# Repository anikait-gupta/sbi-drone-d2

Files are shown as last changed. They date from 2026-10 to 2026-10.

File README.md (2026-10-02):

# sbi-drone-d2

SBI UT club drone. Phase 1 is a quadcopter that flies on an ArduPilot stack capable of autonomous missions. It has no payload or onboard computer yet. The motors, battery and power system are sized for the heavier Phase 2 build, so those can be added later without replacing anything.

## What's here

| Path | Contents |
| :-- | :-- |
| `SBI_Drone_Phase1_Parts.xlsx` | Phase 1 parts list: vendor, price (checked 2026-09-30), link, and why each part was chosen |
| `wiring/` | Phase 1 wiring: block diagram, KiCad schematic, wiring table, and the checks that keep them in sync. See [`wiring/README.md`](wiring/README.md) |

## Phase 1 build

- **Flight controller:** Holybro Pixhawk 6C with PM07 power module and M10 GPS, running ArduPilot
- **Propulsion:** 4x BrotherHobby Avenger 3110 730KV, 4x Hobbywing XRotor Pro 50A ESCs, 10x4.5 props, quad X
- **Power:** 6S 5000 mAh LiPo, XT60
- **RC link:** RadioMaster Pocket (ELRS 2.4 GHz) with an RP3-H receiver on TELEM3
- **Frame:** custom CNC carbon plate, about 450-500 mm wheelbase (CAD in progress)

Not yet priced: frame, McMaster hardware, LiPo bag, microSD card. The onboard computer is deferred to Phase 2.

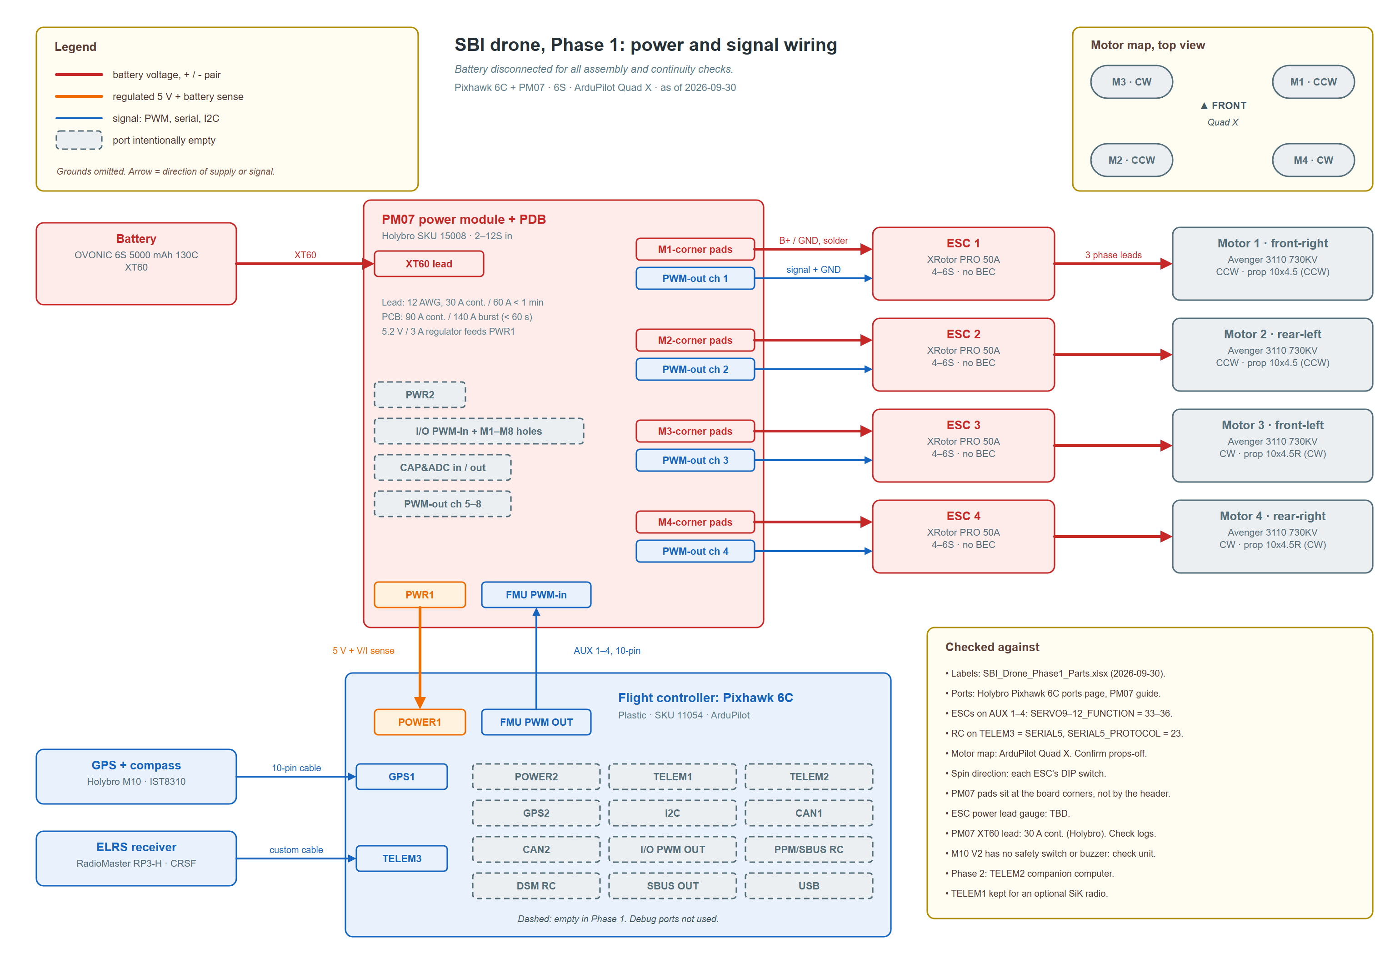
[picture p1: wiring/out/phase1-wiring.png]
Phase 1 wiring block diagram


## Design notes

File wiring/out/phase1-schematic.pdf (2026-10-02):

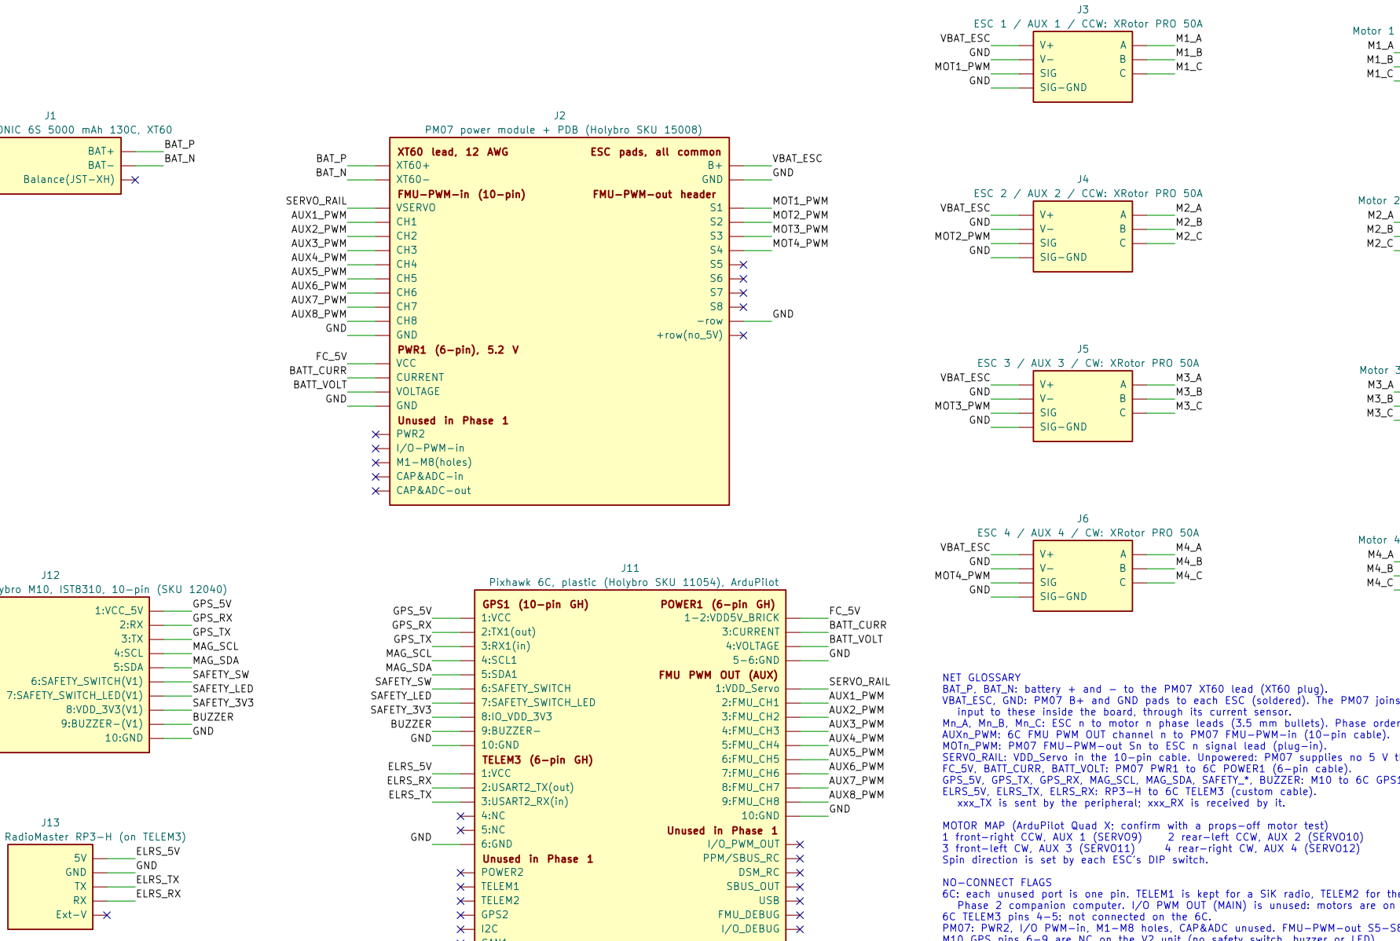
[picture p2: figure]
5V Ext-V GND; Balance(JST-XH) BAT-; BAT+; 1:VCC_5V 2:RX; 3:TX 4:SCL 5:SDA 6:SAFETY_SWITCH(V1); 7:SAFETY_SWITCH_LED(V1) 8:VDD_3V3(V1) 9:BUZZER-(V1) 10:GND; ESC pads, all common; FMU-PWM-out header GND; VSERVO; I/O-PWM-in; M1-M8(holes); -row; S1 S2 S3 S4 S5 S6 S7 S8 +row(no_5V) CURRENT GND; VCC; VOLTAGE PWR2; 1:VDD_Servo 2:FMU_CH1; 3:FMU_CH2 4:FMU_CH3 5:FMU_CH4 6:FMU_CH5 7:FMU_CH6 8:FMU_CH7 9:FMU_CH8 10:GND; FMU_DEBUG; 1:VCC 2:TX1(out) 3:RX1(in) 4:SCL1; 5:SDA1 6:SAFETY_SWITCH 7:SAFETY_SWITCH_LED 8:IO_VDD_3V3 9:BUZZER- 10:GND; GPS2; I/O_DEBUG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

ELRS receiver: RadioMaster RP3-H (on TELEM3)

J1 Battery: OVONIC 6S 5000 mAh 130C, XT60

J12 GPS + compass: Holybro M10, IST8310, 10-pin (SKU 12040) | XT60 lead, 12 AWG

### FMU-PWM-in (10-pin) PWR1 (6-pin), 5.2 V Unused in Phase 1

# CAP&ADC-in CAP&ADC-out CH1 CH2 CH3 CH4 CH5 CH6 CH7 CH8 GND

J2 PM07 power module + PDB (Holybro SKU 15008) | AB

C

J9 Motor 3 front-left CW: Avenger 3110 730KV GPS1 (10-pin GH) TELEM3 (6-pin GH) Unused in Phase 1 | POWER1 (6-pin GH) FMU PWM OUT (AUX) Unused in Phase 1 CAN1 CAN2 | DSM_RC
J11 Pixhawk 6C, plastic (Holybro SKU 11054), ArduPilot | AB
| C

J10 Motor 4 rear-right CW: Avenger 3110 730KV

AB

C

J7 Motor 1 front-right CCW: Avenger 3110 730KV

AB

C

J8 Motor 2 rear-left CCW: Avenger 3110 730KV

M4_C M3_C M2_C Battery disconnected for all assembly and continuity checks. As of 2026-09-30. Ground truth: wiring/wiring-table.md

# SBI drone, Phase 1: wiring schematic

NET GLOSSARY BAT_P, BAT_N: battery + and - to the PM07 XT60 lead (XT60 plug).

VBAT_ESC, GND: PM07 B+ and GND pads to each ESC (soldered). The PM07 joins its
input to these inside the board, through its current sensor. Mn_A, Mn_B, Mn_C: ESC n to motor n phase leads (3.5 mm bullets). Phase order is arbitrary. AUXn_PWM: 6C FMU PWM OUT channel n to PM07 FMU-PWM-in (10-pin cable). MOTn_PWM: PM07 FMU-PWM-out Sn to ESC n signal lead (plug-in). SERVO_RAIL: VDD_Servo in the 10-pin cable. Unpowered: PM07 supplies no 5 V there. FC_5V, BATT_CURR, BATT_VOLT: PM07 PWR1 to 6C POWER1 (6-pin cable).

GPS_5V, GPS_TX, GPS_RX, MAG_SCL, MAG_SDA, SAFETY_*, BUZZER: M10 to 6C GPS1 (10-pin cable).
ELRS_5V, ELRS_TX, ELRS_RX: RP3-H to 6C TELEM3 (custom cable). xxx_TX is sent by the peripheral; xxx_RX is received by it. MOTOR MAP (ArduPilot Quad X; confirm with a props-off motor test) 1 front-right CCW, AUX 1 (SERVO9) | 2 rear-left CCW, AUX 2 (SERVO10) 3 front-left CW, AUX 3 (SERVO11) | 4 rear-right CW, AUX 4 (SERVO12)

Spin direction is set by each ESC's DIP switch. NO-CONNECT FLAGS

6C: each unused port is one pin. TELEM1 is kept for a SiK radio, TELEM2 for the Phase 2 companion computer. I/O PWM OUT (MAIN) is unused: motors are on AUX. 6C TELEM3 pins 4-5: not connected on the 6C. PM07: PWR2, I/O PWM-in, M1-M8 holes, CAP&ADC unused. FMU-PWM-out S5-S8: four ESCs only. M10 GPS pins 6-9 are NC on the V2 unit (no safety switch, buzzer or LED).

Battery balance lead: charger only. RP3-H Ext-V: unused. ArduPilot: SERVO9-12_FUNCTION = 33-36, SERVO1-4_FUNCTION = 0, SERIAL5_PROTOCOL = 23. ESC power lead gauge: TBD.

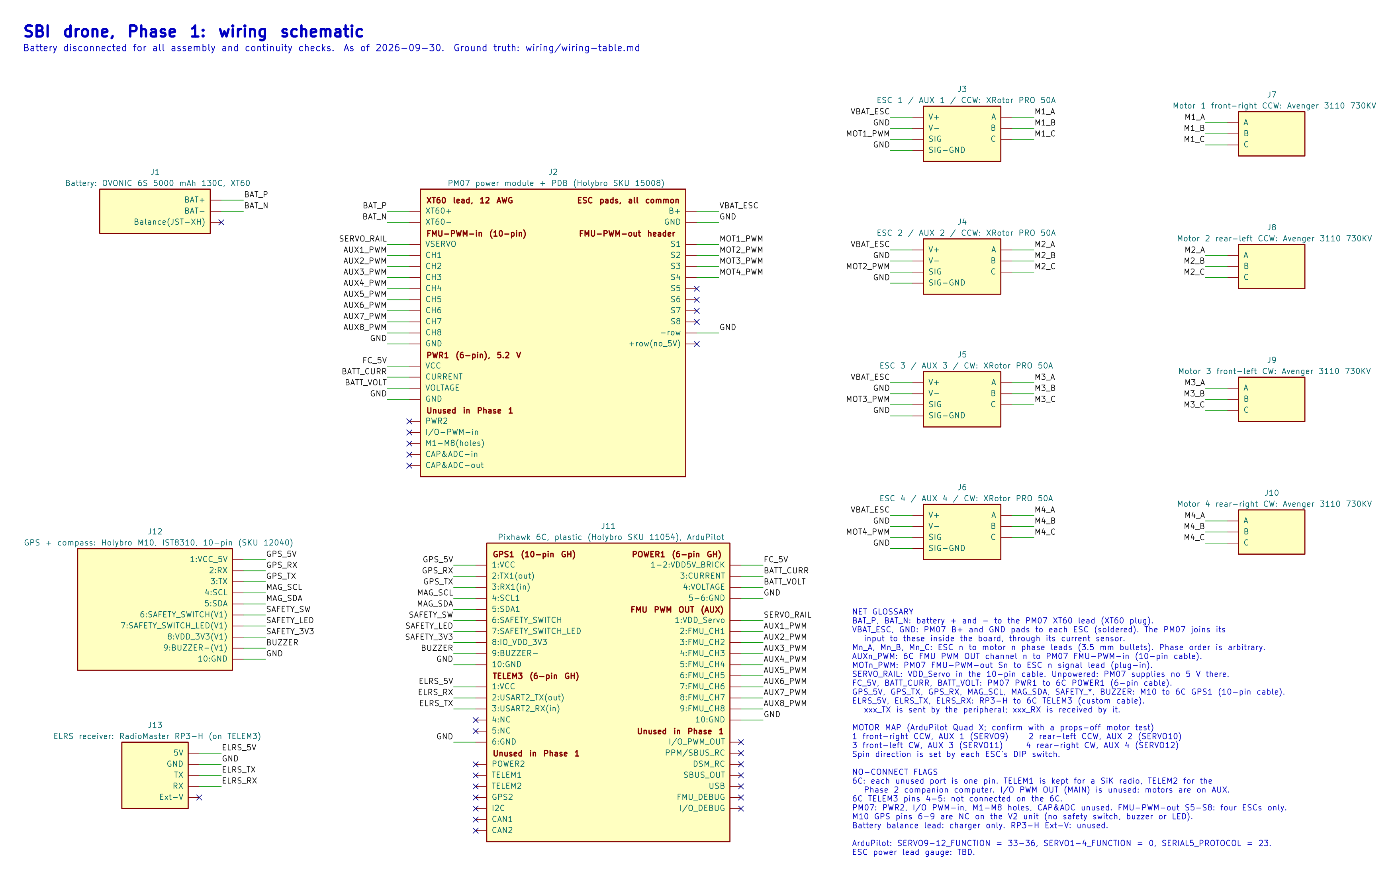
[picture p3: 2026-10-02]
wiring/out/phase1-schematic.png

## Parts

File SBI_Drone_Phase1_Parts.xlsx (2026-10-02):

SBI UT Club Drone - Phase 1 Parts List
Prices and stock verified on vendor pages 2026-09-30. Blue = input; yellow = to fill in / decide.
# | Category | Item | Vendor | Qty | Unit price | Line total | Link | Notes / status | Justification
1 | Flight controller | Pixhawk 6C Plastic + PM07 (SKU 11054+15008) | Holybro | 1 | $242.99 |  | Open (https://holybro.com/products/pixhawk-6c) | Price rose from $209.98. PM07 doubles as PDB. | Runs ArduPilot, which gives us the autonomous waypoint missions and return-to-launch on lost link that Anikait asked for. Two redundant IMUs, both temperature-controlled and vibration-isolated. Spare ports (TELEM1/2, GPS2, CAN) leave room for the Phase 2 companion computer, rangefinder and RTK without changing boards. The PM07 reads battery voltage/current for the low-battery failsafe and doubles as the power distribution board (rated 2-12S), so no separate PDB. Plastic case is the lighter 6C version (34.6 g vs 59.3 g aluminum).
2 | Flight controller | M10 GPS, IST8310, Standard 10-pin (SKU 12040) | Holybro | 1 | $43.99 |  | Open (https://holybro.com/products/m10-gps) | Includes carbon GPS mount. | GPS is required for position hold, waypoint missions and return-to-launch. The IST8310 compass sits on the mast, away from motor and battery current, so heading is cleaner than with the FC's internal compass. Same vendor and standard 10-pin plug as the 6C, so it plugs into GPS1 with no cable work. RTK was 'if budget allows'; GPS2 stays free for it later.
3 | Propulsion | BrotherHobby Avenger 3110 730KV (select 730) | AeromotorFPV | 5 | $29.50 |  | Open (https://www.aeromotorfpv.com/product/brotherhobby-avenger-3110-brushless-motor-cw-730kv-900kv-for-6s-m5-shaft-19x19mm-mount/) | 4 + 1 spare. Sale price ($59 list). | Sized for Phase 2 weight, not just Phase 1: at ~2.2-2.5 kg all-up we need ~1.1-1.25 kg max thrust per motor for a 2:1 thrust-to-weight ratio. Vendor test shows 3017 gf peak (on a 10x5 tri-blade), so there is margin even with our lighter-loading 2-blade prop. 730 KV is the right speed for 10" props on 6S (the 900 KV version is meant for 8-9" props). T-Motor MN3110 rejected as an unneeded premium for Phase 1. Fifth motor is a spare so one bad motor doesn't ground the drone.
4 | Propulsion | Hobbywing XRotor PRO 50A wire-leaded ESC (dual pack) | Hobbywing Direct | 2 | $74.99 |  | Open (https://www.hobbywingdirect.com/collections/xrotor-pro-esc/products/xrotor-pro-50a-esc-dual-pack) | 4-6S, 3.5 mm bullets on motor side, no BEC. | Four separate ESCs rather than a 4-in-1 board (team decision): a failed ESC is one cheap swap, not a whole board. 50 A continuous / 100 A peak gives headroom over the motor's 37.6 A max; 40 A ESCs were too tight at full throttle. Rated 4-6S. Motor side ships with 3.5 mm bullets (less soldering), and a DIP switch sets spin direction, so all five motors can be the same part. Standard PWM input works with ArduPilot on the 6C. No BEC needed because the PM07 powers the FC.
5 | Propulsion | HQProp MR 10x4.5 CCW (single prop) | HQProp | 6 | $2.91 |  | Open (https://hqprop.com/multi-rotor-prop-p0155.html) | Ships from China; shipping not shown. GetFPV out of stock. | 10" diameter matches the 730 KV / 6S motors and the 450-500 mm frame. Glass-fiber reinforced nylon is cheap and more forgiving in crashes than carbon; carbon props are deferred to Phase 2 benchmarking. A quad X needs 2 CCW + 2 CW per set, so 6 of each = 3 full sets, since props are the most common crash casualty. 5 mm ring fits the Avenger's M5 shaft. Bought direct because GetFPV is out of stock.
6 | Propulsion | HQProp MR 10x4.5R CW (single prop) | HQProp | 6 | $2.91 |  | Open (https://hqprop.com/multi-rotor-pusher-prop-10x45rcw-p0300.html) | Ships from China; 5 mm ring included. | CW half of each prop set (see #5). A quad X spins two motors each way so their torques cancel, which is what lets the FC control yaw.
7 | Propulsion | JFtech 3.5 mm gold bullets, 20 pairs + heat shrink | Amazon | 1 | $7.99 |  | Open (https://www.amazon.com/dp/B07C69VDV3) | Males go on bare Avenger motor leads. | Avenger motors ship with bare leads; the ESCs already have 3.5 mm bullets. Putting matching bullets on the 15 motor leads (5 motors x 3) makes motors plug-and-unplug, so a bad motor is swapped without desoldering. 20 pairs covers that with spares, and the heat shrink insulates each joint.
8 | Power | OVONIC 6S 5000mAh 130C XT60 (2-pack) | Amazon | 1 | $110.99 |  | Open (https://www.amazon.com/dp/B0DNLWDTDT) | PENDING OK: replaces CNHL (out of US stock). XT60 = no adapter. | 6S matches the 730 KV motors: higher voltage means less current for the same power, so less heat in the ESCs and wiring. XT60 plugs straight into the PM07, so no adapter (one less joint to loosen or heat up). 130C is far above our peak draw (~150 A, four motors at 37.6 A). The 2-pack works out to $55.50 per pack, about what one CNHL cost, and the second pack doubles flight time per test session since a recharge takes ~2 h.
9 | Charging | SkyRC B6 Neo charger | Amazon | 1 | $37.50 |  | Open (https://www.amazon.com/dp/B0CCT2WGNS) | Sold by YEERSINS, ships from Amazon. | LiPos have to be balance charged on a proper hobby charger. The B6 Neo does 1-6S balance charging plus storage-voltage mode, which extends pack life between test days, and it's one of the cheapest 6S-capable chargers. Runs from USB-C PD (80 W, ~3 A, ~1.7-2 h per pack) or a DC supply up to 200 W if we want faster charging later.
10 | Charging | VUOHOEG 100W USB-C PD charger (built-in cable) | Amazon | 1 | $18.89 |  | Open (https://www.amazon.com/dp/B0FBG4BY5X) | Powers B6 Neo at 80W via USB-C. | The B6 Neo has no built-in AC power; it needs a 100 W (20 V / 5 A) USB-C PD source or a DC supply. This is the cheapest working option and its cable is built in and 5 A rated, so no separate 5 A cable to buy. A 24 V DC supply (~$30) would charge faster but isn't needed yet. Unbranded, but 4.3 stars over 692 reviews.
11 | RC link | RadioMaster Pocket, Charcoal / ELRS / FCC (M2) | RadioMaster | 1 | $71.50 |  | Open (https://radiomasterrc.com/products/pocket-radio-controller-m2) | Batteries not included. | A handheld radio is needed for manual takeoff/landing while tuning and as the safety pilot's override during autonomous flights; nobody on the team owns one. ELRS 2.4 GHz has long range, low latency and sends telemetry (link quality, battery voltage) back to the radio. The Pocket is one of the cheapest full EdgeTX radios. FCC version for US use; Mode 2 is the standard US stick layout. FlySky i6X rejected: no telemetry and shorter range.
12 | RC link | RadioMaster 18650 3200mAh (2 pcs) | RadioMaster | 1 | $11.99 |  | Open (https://radiomasterrc.com/products/18650-3200mah-3-7v-battery-2pcs-for-tx16s-boxer-tx12-mt12-radios) | Must be bought in same order as radio. | The Pocket runs on 2x 18650 cells that aren't included. RadioMaster's own cells are made for its radios, and ordering them with the Pocket and RP3-H keeps it to one shipment.
13 | RC link | RadioMaster RP3-H receiver (FCC) | RadioMaster | 1 | $19.99 |  | Open (https://radiomasterrc.com/products/rp3-h-expresslrs-2-4ghz-nano-receiver) | JST-GH 4-pin cables included. | ELRS receiver that pairs with the Pocket. One serial (CRSF) cable to TELEM3 carries both stick inputs and telemetry, and ArduPilot supports it natively; losing the link triggers the RC failsafe (RTL). Two diversity antennas for a steadier link than single-antenna receivers, 100 mW telemetry, 5.1 g.
14 | RC link | elechawk GH1.25 to Dupont pre-crimped cable kit | Amazon | 1 | $20.99 |  | Open (https://amazon.com/Dupont2-54-Pre-Crimped-Connectors-Pixhawk4-Pixhawk2/dp/B087N4GY8Z) | Build 6-pin GH cable to TELEM port. | The RP3-H comes with 4-pin JST-GH cables, but the 6C's TELEM ports are 6-pin JST-GH. Pre-crimped GH wires and housings let us build the right 6-pin cable without a crimping tool. Leftovers cover Phase 2 wiring (companion computer on TELEM2, rangefinder).
Still to price (fill in when quoted)
15 | Frame | CNC carbon frame (CNC Madness quote) | CNC Madness | 1 |  |  |  | Needs CAD; ~450-500 mm class. | Team chose a custom frame over off-the-shelf kits (S500/X500) so it can be laid out for the Phase 2 payload mount and compute bay from the start. CNC carbon plate is stiff and light, and a ~450-500 mm wheelbase clears 10" props. CNC Madness turns quotes around quickly, so the price comes once CAD is done.
16 | Hardware | McMaster hardware (M3 standoffs/screws, M5 nyloc nuts, etc.) | McMaster-Carr | 1 |  |  |  | Depends on frame design. | Fasteners and standoffs to assemble the frame and mount the electronics, plus spare M5 nyloc nuts for the props (nyloc won't vibrate loose). McMaster lists exact dimensions and ships fast; quantities get set once the CAD is final.
17 | Misc | LiPo safety bag |  | 1 |  |  |  | If club has none. | Damaged or overcharged LiPos can catch fire. Charging and storing packs in a fire-resistant bag is standard practice, and we will have two 6S packs in a shared campus lab. Skip if the club already has one.
18 | Misc | microSD card (<=32 GB) for flight logs |  | 1 |  |  |  | Not listed in 6C box contents. | ArduPilot writes its flight logs to this card; we need them to tune PIDs, check vibration and work out what went wrong after a crash. The 6C box contents don't list a card. 32 GB or smaller ships formatted FAT32, which the FC reads without reformatting.
 |  |  |  | Verified subtotal
 |  |  |  | Still-to-price subtotal
 |  |  |  | Budget |  | $1300.00
 |  |  |  | Est. sales tax rate |  | 8.25%
 |  |  |  | Est. shipping (all vendors) |  | $0.00
 |  |  |  | Est. tax
 |  |  |  | Est. grand total
 |  |  |  | Remaining budget

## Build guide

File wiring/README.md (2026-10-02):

# Phase 1 wiring figures

There are two figures of the same wiring, built from two separate sources. The method comes from `drone-docs/outputs/wiring-pipeline-handoff.md`.

| Figure | For | Source of truth | Output |
| :-- | :-- | :-- | :-- |
| Block diagram | Assembly: what connects to what, colour coded by rail | `phase1_wiring.py`, drawn by `wiring_diagram.py` | `out/phase1-wiring.svg`, `.drawio`, `.png` |
| Schematic | Verification: pin names and named nets | `kicad/sbi_phase1.kicad_sch` and `kicad/sbi_phase1.kicad_sym` | `out/phase1-schematic.pdf`, `.png` |

Both are drawn from `wiring-table.md`, which cites a source for every conductor.

## Rebuild and check

```
pip install playwright pymupdf pillow
playwright install chromium
python build.py
```

`build.py` runs the layout linter, KiCad ERC, and the netlist check against `kicad/expected-nets.txt`, then exports the PDF and PNG. It exits 1 if any check fails. After it passes, look at both PNGs: the checks cover geometry and connectivity, not whether the figure is correct.

## Changing a wiring fact

1. Change it in `wiring-table.md`.
2. Change it in `phase1_wiring.py`.
3. Change it in the schematic (KiCad GUI, or the text file), then the matching line in `kicad/expected-nets.txt`.
4. Run `python build.py`, then grep all of the above for the old value.

`kicad/gen_schematic.py` wrote the first version of the KiCad files. Once anyone edits the schematic in KiCad, do not run it again: it overwrites the schematic, the library and the project file.

The `.drawio` file is for anyone who wants to hand-tweak the layout in diagrams.net. A hand edit is lost the next time `phase1_wiring.py` runs.

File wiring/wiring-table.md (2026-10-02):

# Phase 1 wiring table

Ground truth for both wiring figures (`out/phase1-wiring.*` and `kicad/sbi_phase1.kicad_sch`). If a wiring fact changes, change it here first, then in `phase1_wiring.py`, then in the schematic, and run the netlist check.

As of 2026-09-30. Battery disconnected for all assembly and continuity checks.

## Sources

| Key | Source |
| :-- | :-- |
| BOM | `SBI_Drone_Phase1_Parts.xlsx`, prices and stock verified 2026-09-30 |
| 6C | Holybro, [Pixhawk 6C Ports](https://docs.holybro.com/autopilot/pixhawk-6c/pixhawk-6c-ports) |
| PM07 | Holybro, [PM07 Quick Start Guide](https://docs.holybro.com/power-module-and-pdb/power-module/pm07-quick-start-guide), including its board-tracing image |
| GPS | Holybro, [Standard M10 GPS overview](https://docs.holybro.com/gps-and-rtk-system/m8n-m9n-m10-gps/standard-m10-m9n-m8n-gps/overview) and [pinout](https://docs.holybro.com/gps-and-rtk-system/m8n-m9n-m10-gps/standard-m10-m9n-m8n-gps/pinout) images |
| AP | ArduPilot, [Holybro Pixhawk 6C](https://ardupilot.org/copter/docs/common-holybro-pixhawk6C.html) and [Connect ESCs and motors](https://ardupilot.org/copter/docs/connect-escs-and-motors.html) (Quad X image `m_01_01_quad_x1.svg`) |
| HW | Hobbywing, [XRotor PRO 50A dual pack](https://www.hobbywingdirect.com/products/xrotor-pro-50a-esc-dual-pack) |
| RM | RadioMaster, [RP3-H](https://radiomasterrc.com/products/rp3-h-expresslrs-2-4ghz-nano-receiver) |
| TEAM | Decisions made 2026-09-30: OVONIC battery approved, ELRS on TELEM3, ArduPilot Quad X map, ESC signals through the PM07 AUX header |

## Components

| Ref | Component | Label source |
| :-- | :-- | :-- |
| J1 | Battery: OVONIC 6S 5000 mAh 130C, XT60 | BOM #8, TEAM |
| J2 | PM07 power module + PDB (Holybro SKU 15008) | BOM #1 |
| J3 to J6 | ESC 1 to 4: Hobbywing XRotor PRO 50A, 4 to 6S, no BEC | BOM #4, HW |
| J7 to J10 | Motor 1 to 4: BrotherHobby Avenger 3110 730KV | BOM #3 |
| J11 | Pixhawk 6C, plastic (Holybro SKU 11054), ArduPilot | BOM #1 |
| J12 | GPS + compass: Holybro M10, IST8310, standard 10-pin (SKU 12040) | BOM #2, GPS |
| J13 | ELRS receiver: RadioMaster RP3-H | BOM #13, RM |

## Conductors

### Battery voltage

| ID | From | To | Carries | Connector or joint | Gauge | Source |
| :-- | :-- | :-- | :-- | :-- | :-- | :-- |
| P1 | J1 battery lead | J2 PM07 XT60 lead | BAT+ / BAT- | XT60 plug | PM07 lead 12 AWG; battery lead not recorded | BOM, PM07 |
| P2 | J2 B+ / GND pads | J3 ESC 1 power leads | V+ / V- | Solder to pads | TBD (not on the Hobbywing page) | BOM, PM07 |
| P3 | J2 B+ / GND pads | J4 ESC 2 power leads | V+ / V- | Solder to pads | TBD | BOM, PM07 |
| P4 | J2 B+ / GND pads | J5 ESC 3 power leads | V+ / V- | Solder to pads | TBD | BOM, PM07 |
| P5 | J2 B+ / GND pads | J6 ESC 4 power leads | V+ / V- | Solder to pads | TBD | BOM, PM07 |
| P6 to P9 | ESC n motor output, 3 leads | Motor n phase leads, 3 | Phase A, B, C | ESC side has 3.5 mm bullets fitted; solder JFtech 3.5 mm male bullets onto the bare motor leads | Not recorded | BOM #3, #4, #7, HW |

- The PM07 has four corner pad groups, each `GND B+ B+ GND`, so each group serves two ESCs. All B+ pads are common and all GND pads are common. Suggested: put ESC n on the group at the corner marked `Mn`. Seen from above, those corners match the Quad X map if the XT60 edge of the PM07 faces the rear (inferred from the PM07 silkscreen, not stated by Holybro).
- Holybro rates the PM07's XT60 and 12 AWG lead at 30 A continuous and 60 A for under 1 minute. The PCB is rated 90 A continuous and 140 A burst (under 60 s). See open item 3.
- Motor phase order is arbitrary. Each ESC's DIP switch sets spin direction.

### Regulated 5 V and battery sense

| ID | From | To | Carries | Connector | Source |
| :-- | :-- | :-- | :-- | :-- | :-- |
| F1 | J2 PWR1 | J11 POWER1 | Pins 1-2 VCC 5 V, 3 CURRENT, 4 VOLTAGE, 5-6 GND | 6-pin JST-GH cable (supplied with PM07) | PM07, 6C |

- The PM07 supplies regulated 5.2 V at up to 3 A. ArduPilot defaults for POWER1: `BATT_MONITOR=4`, `BATT_VOLT_PIN=8`, `BATT_CURR_PIN=4`, `BATT_VOLT_MULT=18.182`, `BATT_AMP_PERVLT=36.364` (AP).

### Signal

| ID | From | To | Carries | Connector | Source |
| :-- | :-- | :-- | :-- | :-- | :-- |
| S1 | J11 FMU PWM OUT (AUX) | J2 FMU-PWM-in | Pin 1 VDD_Servo, 2-9 FMU_CH1-8, 10 GND | 10-pin JST-GH cable | 6C, PM07, TEAM |
| S2 | J2 FMU-PWM-out channel 1 (S and -) | J3 ESC 1 signal lead | AUX 1 PWM + signal ground | ESC signal plug onto the 3-pin header | PM07, TEAM |
| S3 | J2 FMU-PWM-out channel 2 | J4 ESC 2 signal lead | AUX 2 PWM | as S2 | PM07, TEAM |
| S4 | J2 FMU-PWM-out channel 3 | J5 ESC 3 signal lead | AUX 3 PWM | as S2 | PM07, TEAM |
| S5 | J2 FMU-PWM-out channel 4 | J6 ESC 4 signal lead | AUX 4 PWM | as S2 | PM07, TEAM |
| S6 | J12 GPS 10-pin | J11 GPS1 | 1 VCC, 2 RX, 3 TX, 4 SCL, 5 SDA, 6 SAFETY_SWITCH, 7 SAFETY_SWITCH_LED, 8 VDD_3V3, 9 BUZZER-, 10 GND (GPS-side names, V1) | 10-pin JST-GH cable, 26 cm, supplied | GPS, 6C |
| S7 | J13 RP3-H | J11 TELEM3 | 5V to pin 1 VCC; receiver TX to pin 3 USART2_RX; receiver RX to pin 2 USART2_TX; GND to pin 6. Pins 4-5 empty | Custom cable: RP3-H 4-pin JST-GH lead joined to a 6-pin JST-GH from the elechawk kit | BOM #13, #14, 6C, TEAM |

- The PM07's FMU-PWM-out `+` row carries no 5 V (Holybro). The XRotor PRO has no BEC and needs none, so this is fine.
- ArduPilot: `SERVO9_FUNCTION=33`, `SERVO10_FUNCTION=34`, `SERVO11_FUNCTION=35`, `SERVO12_FUNCTION=36` (Motor 1 to 4 on AUX 1 to 4). Set `SERVO1_FUNCTION` to `SERVO4_FUNCTION` to 0 so the unused MAIN outputs carry no motor signal.
- ArduPilot: TELEM3 is `SERIAL5`. Set `SERIAL5_PROTOCOL=23` (RCIN) for CRSF. ArduPilot says ELRS needs a full UART, so the RC IN port cannot be used (AP).
- RP3-H working voltage is 4.5 to 8.4 V (RM), so TELEM3's 5 V supply is in range.

## Motor map (ArduPilot Quad X)

| Motor | Position | Spin | Prop | ESC | Output |
| :-- | :-- | :-- | :-- | :-- | :-- |
| 1 | front-right | CCW | HQProp MR 10x4.5 (CCW) | ESC 1 | AUX 1 (SERVO9) |
| 2 | rear-left | CCW | HQProp MR 10x4.5 (CCW) | ESC 2 | AUX 2 (SERVO10) |
| 3 | front-left | CW | HQProp MR 10x4.5R (CW) | ESC 3 | AUX 3 (SERVO11) |
| 4 | rear-right | CW | HQProp MR 10x4.5R (CW) | ESC 4 | AUX 4 (SERVO12) |

Not yet confirmed on hardware. Confirm with a props-off motor test in Mission Planner before fitting props.

## Ports left empty in Phase 1

Every port is accounted for. These are empty on purpose.

| Board | Port | Why empty |
| :-- | :-- | :-- |
| 6C | POWER2 | One power module only |
| 6C | TELEM1 | Kept for an optional SiK telemetry radio |
| 6C | TELEM2 | Kept for the Phase 2 companion computer |
| 6C | GPS2, I2C, CAN1, CAN2 | No second GPS or other sensors in Phase 1 |
| 6C | I/O PWM OUT (MAIN) | Motors are on AUX |
| 6C | PPM/SBUS RC, DSM RC, SBUS OUT | ELRS uses TELEM3 |
| 6C | USB | Laptop link for setup only, not wired on the aircraft |
| 6C | FMU DEBUG, I/O DEBUG | Not used |
| PM07 | PWR2 | One flight controller power port in use |
| PM07 | I/O PWM-in and the M1-M8 solder holes | Motors are on AUX |
| PM07 | FMU-PWM-out channels 5-8 | Only four ESCs |
| PM07 | CAP&ADC-in, CAP&ADC-out | The 6C has no CAP&ADC port |
| PM07 | Second B+ / GND pair at each corner | Only four ESCs |
| J1 | Balance lead (JST-XH) | Charger only |
| J13 | Ext-V input | Not used |

Not wiring, but on the list: the microSD card goes in the 6C's slot. The charger, the Pocket transmitter and the 100 W USB-C supply stay on the ground.

## Open items

1. **ESC power lead gauge.** The Hobbywing page does not state it. Retailer listings say 14 AWG; check on arrival and record it here.
2. **ESC signal plug.** Confirm on arrival that the XRotor PRO signal lead ends in a plug that fits the PM07's 2.54 mm 3-pin header, with signal on S and ground on -.
3. **PM07 input lead rating.** 30 A continuous, 60 A for under 1 minute (Holybro), against four 50 A ESCs and motors listed at 37.6 A max each. Fine for hover; check measured current in the first flight logs before aggressive flying. Holybro says to change the plug and wire for higher current.
4. **GPS version.** M10 V2 has no safety switch, buzzer or safety LED (pins 6-9 are NC). The 6C has no safety switch of its own. If a V2 unit arrives, disable the safety switch in ArduPilot (`BRD_SAFETY_DEFLT=0`) and expect no buzzer.
5. **Motor map** confirmed only by a props-off motor test.
6. **Frame layout.** Wire lengths and PM07 orientation depend on the CNC frame CAD.

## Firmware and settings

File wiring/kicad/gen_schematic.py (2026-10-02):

# -*- coding: utf-8 -*-
"""Write the first version of the Phase 1 KiCad project: symbol library, schematic, project file.

Nets are built from named local labels on short wire stubs; the same name means the same net.
Every pin is either labelled or carries a no-connect flag.

After this has run, sbi_phase1.kicad_sch is the source of truth. If you edit the schematic in
KiCad, do not run this again: it overwrites the schematic, the library and the project file.

Run: python gen_schematic.py
"""
import json, os, uuid

LIB = "sbi_phase1"
NS = uuid.UUID("6f1d9a52-4c3e-4f5e-9a0b-2b7f3d1e5c80")     # fixed, so regenerating gives the same UUIDs
G = 1.27                                                   # KiCad connection grid, mm
FONT = "(effects (font (size 1.27 1.27)))"
FONT_HIDE = "(effects (font (size 1.27 1.27)) (hide yes))"


def uid(*key):
    return str(uuid.uuid5(NS, "/".join(map(str, key))))


def f(v):
    s = ("%.4f" % v).rstrip("0").rstrip(".")
    return "0" if s in ("-0", "") else s


def q(s):
    return '"%s"' % s.replace("\\", "\\\\").replace('"', '\\"').replace("\n", "\\n")


# ---------------------------------------------------------------- symbols
# Each side is a list of rows, top to bottom: ("H", heading) is a heading row drawn inside the
# body, None is an empty row, and (number, name, electrical type) is a pin. Pin numbers are
# hidden; names carry the signal, prefixed with the connector pin where Holybro documents it.
def P(num, name, etype="passive"):
    return (num, name, etype)


SYMBOLS = {
    "Battery": dict(desc="LiPo battery pack", right=[
        P("BATP", "BAT+", "power_out"), P("BATN", "BAT-"), P("BAL", "Balance(JST-XH)")]),

    "PM07": dict(desc="Holybro PM07 power module and PDB", left=[
        ("H", "XT60 lead, 12 AWG"),
        P("XT60P", "XT60+", "power_in"), P("XT60N", "XT60-"),
        ("H", "FMU-PWM-in (10-pin)"),
        P("FIN_V", "VSERVO")] + [P("FIN_CH%d" % i, "CH%d" % i, "input") for i in range(1, 9)] + [
        P("FIN_GND", "GND"),
        ("H", "PWR1 (6-pin), 5.2 V"),
        P("PWR1_VCC", "VCC", "power_out"), P("PWR1_CUR", "CURRENT", "output"),
        P("PWR1_VOLT", "VOLTAGE", "output"), P("PWR1_GND", "GND"),
        ("H", "Unused in Phase 1"),
        P("PWR2", "PWR2"), P("IOIN", "I/O-PWM-in"), P("MHOLES", "M1-M8(holes)"),
        P("CAPIN", "CAP&ADC-in"), P("CAPOUT", "CAP&ADC-out")],
        right=[
        ("H", "ESC pads, all common"),
        P("BP", "B+", "power_out"), P("BN", "GND", "power_out"),
        ("H", "FMU-PWM-out header")] + [P("OUT_S%d" % i, "S%d" % i, "output") for i in range(1, 9)] + [
        P("OUT_GND", "-row"), P("OUT_V", "+row(no_5V)")]),

    "ESC": dict(desc="Brushless ESC, no BEC", left=[
        P("VP", "V+", "power_in"), P("VN", "V-", "power_in"),
        P("SIG", "SIG", "input"), P("SGND", "SIG-GND")],
        right=[P("A", "A", "output"), P("B", "B", "output"), P("C", "C", "output")]),

    "Motor": dict(desc="Brushless motor", left=[P("A", "A"), P("B", "B"), P("C", "C")]),

    "Pixhawk6C": dict(desc="Holybro Pixhawk 6C flight controller", left=[
        ("H", "GPS1 (10-pin GH)"),
        P("GPS1_1", "1:VCC", "power_out"), P("GPS1_2", "2:TX1(out)", "output"),
        P("GPS1_3", "3:RX1(in)", "input"), P("GPS1_4", "4:SCL1", "bidirectional"),
        P("GPS1_5", "5:SDA1", "bidirectional"), P("GPS1_6", "6:SAFETY_SWITCH", "input"),
        P("GPS1_7", "7:SAFETY_SWITCH_LED", "output"), P("GPS1_8", "8:IO_VDD_3V3", "power_out"),
        P("GPS1_9", "9:BUZZER-", "output"), P("GPS1_10", "10:GND"),
        ("H", "TELEM3 (6-pin GH)"),
        P("TELEM3_1", "1:VCC", "power_out"), P("TELEM3_2", "2:USART2_TX(out)", "output"),
        P("TELEM3_3", "3:USART2_RX(in)", "input"), P("TELEM3_4", "4:NC"), P("TELEM3_5", "5:NC"),
        P("TELEM3_6", "6:GND"),
        ("H", "Unused in Phase 1")] + [P(n, n) for n in
        ("POWER2", "TELEM1", "TELEM2", "GPS2", "I2C", "CAN1", "CAN2")],
        right=[
        ("H", "POWER1 (6-pin GH)"),
        P("POWER1_1", "1-2:VDD5V_BRICK", "power_in"), P("POWER1_3", "3:CURRENT", "input"),
        P("POWER1_4", "4:VOLTAGE", "input"), P("POWER1_5", "5-6:GND", "power_in"),
        ("H", "FMU PWM OUT (AUX)"),
        P("FMU_1", "1:VDD_Servo")] + [P("FMU_%d" % (i + 1), "%d:FMU_CH%d" % (i + 1, i), "output")
                                      for i in range(1, 9)] + [
        P("FMU_10", "10:GND"),
        ("H", "Unused in Phase 1")] + [P(n.replace("/", "_"), n) for n in
        ("I/O_PWM_OUT", "PPM/SBUS_RC", "DSM_RC", "SBUS_OUT", "USB", "FMU_DEBUG", "I/O_DEBUG")]),

    "GPS_M10": dict(desc="Holybro M10 GPS, standard 10-pin", right=[
        P("1", "1:VCC_5V", "power_in"), P("2", "2:RX", "input"), P("3", "3:TX", "output"),
        P("4", "4:SCL", "bidirectional"), P("5", "5:SDA", "bidirectional"),
        P("6", "6:SAFETY_SWITCH(V1)"), P("7", "7:SAFETY_SWITCH_LED(V1)"),
        P("8", "8:VDD_3V3(V1)"), P("9", "9:BUZZER-(V1)"), P("10", "10:GND", "power_in")]),

    "ELRS_RX": dict(desc="ExpressLRS receiver, CRSF", right=[
        P("5V", "5V", "power_in"), P("GND", "GND", "power_in"), P("TX", "TX", "output"),
        P("RX", "RX", "input"), P("EXTV", "Ext-V")]),
}
CHAR = 1.12          # mm per character at 1.27 mm text, a deliberately wide estimate


def geometry(sym):
    left, right = sym.get("left", []), sym.get("right", [])
    rows = max(len(left), len(right))
    # headings are bold, so count them wider than pin names
    width = lambda side: max([len(r[1]) * (1.2 if r[0] == "H" else 1.0) for r in side if r] or [0])
    need = (width(left) + width(right)) * CHAR + 8
    w = 2 * int(-(-need // (2 * G)))                       # body width in grid units, even
    w = max(w, 12)
    top = rows + 1                                         # grid units, body is symmetric
    pins = []                                              # (num, name, type, side, x, y) in mm, y up
    for side, rows_ in (("L", left), ("R", right)):
        for k, r in enumerate(rows_):
            if r and r[0] != "H":
                x = (-(w // 2) - 2) * G if side == "L" else ((w // 2) + 2) * G
                pins.append((r[0], r[1], r[2], side, x, (rows - 1 - 2 * k) * G))
    heads = [(side, (rows - 1 - 2 * k) * G, r[1])
             for side, rows_ in (("L", left), ("R", right)) for k, r in enumerate(rows_)
             if r and r[0] == "H"]
    return dict(w=w * G, top=top * G, pins=pins, heads=heads)


def symbol_sexpr(name, sym, prefix=""):
    g = geometry(sym)
    hw, top = g["w"] / 2, g["top"]
    out = ['(symbol %s (pin_numbers hide) (pin_names (offset 1.016)) (exclude_from_sim no) '
           '(in_bom yes) (on_board yes)' % q(prefix + name),
           '  (property "Reference" "J" (at 0 %s 0) %s)' % (f(top + 3.81), FONT),
           '  (property "Value" %s (at 0 %s 0) %s)' % (q(name), f(top + 1.27), FONT),
           '  (property "Footprint" "" (at 0 0 0) %s)' % FONT_HIDE,
           '  (property "Datasheet" "" (at 0 0 0) %s)' % FONT_HIDE,
           '  (property "Description" %s (at 0 0 0) %s)' % (q(sym["desc"]), FONT_HIDE),
           '  (symbol %s' % q("%s_0_1" % name),
           '    (rectangle (start %s %s) (end %s %s) (stroke (width 0.254) (type default)) '
           '(fill (type background)))' % (f(-hw), f(top), f(hw), f(-top))]
    for side, y, s in g["heads"]:
        x, just = (-hw + 1.27, "left") if side == "L" else (hw - 2.54, "right")
        out.append('    (text %s (at %s %s 0) (effects (font (size 1.27 1.27) (bold yes)) (justify %s)))'
                   % (q(s), f(x), f(y), just))
    out.append('  )')
    out.append('  (symbol %s' % q("%s_1_1" % name))
    for num, pname, etype, side, x, y in g["pins"]:
        out.append('    (pin %s line (at %s %s %d) (length 2.54) (name %s %s) (number %s %s))'
                   % (etype, f(x), f(y), 0 if side == "L" else 180, q(pname), FONT, q(num), FONT))
    out.append('  )')
    out.append(')')
    return "\n".join(out)


# ---------------------------------------------------------------- placement and nets
# (ref, symbol, value, x, y, {pin number: net name or None for a no-connect})
NC = None
PARTS = [
    ("J1", "Battery", "Battery: OVONIC 6S 5000 mAh 130C, XT60", 50.8, 60.96,
     {"BATP": "BAT_P", "BATN": "BAT_N", "BAL": NC}),
    ("J2", "PM07", "PM07 power module + PDB (Holybro SKU 15008)", 142.24, 88.9, dict(
        [("XT60P", "BAT_P"), ("XT60N", "BAT_N"), ("FIN_V", "SERVO_RAIL"), ("FIN_GND", "GND"),
         ("PWR1_VCC", "FC_5V"), ("PWR1_CUR", "BATT_CURR"), ("PWR1_VOLT", "BATT_VOLT"), ("PWR1_GND", "GND"),
         ("PWR2", NC), ("IOIN", NC), ("MHOLES", NC), ("CAPIN", NC), ("CAPOUT", NC),
         ("BP", "VBAT_ESC"), ("BN", "GND"), ("OUT_GND", "GND"), ("OUT_V", NC)]
        + [("FIN_CH%d" % i, "AUX%d_PWM" % i) for i in range(1, 9)]
        + [("OUT_S%d" % i, "MOT%d_PWM" % i if i <= 4 else NC) for i in range(1, 9)])),
    ("J11", "Pixhawk6C", "Pixhawk 6C, plastic (Holybro SKU 11054), ArduPilot", 154.94, 171.45, dict(
        [("GPS1_1", "GPS_5V"), ("GPS1_2", "GPS_RX"), ("GPS1_3", "GPS_TX"), ("GPS1_4", "MAG_SCL"),
         ("GPS1_5", "MAG_SDA"), ("GPS1_6", "SAFETY_SW"), ("GPS1_7", "SAFETY_LED"),
         ("GPS1_8", "SAFETY_3V3"), ("GPS1_9", "BUZZER"), ("GPS1_10", "GND"),
         ("TELEM3_1", "ELRS_5V"), ("TELEM3_2", "ELRS_RX"), ("TELEM3_3", "ELRS_TX"),
         ("TELEM3_4", NC), ("TELEM3_5", NC), ("TELEM3_6", "GND"),
         ("POWER1_1", "FC_5V"), ("POWER1_3", "BATT_CURR"), ("POWER1_4", "BATT_VOLT"), ("POWER1_5", "GND"),
         ("FMU_1", "SERVO_RAIL"), ("FMU_10", "GND")]
        + [("FMU_%d" % (i + 1), "AUX%d_PWM" % i) for i in range(1, 9)]
        + [(n, NC) for n in ("POWER2", "TELEM1", "TELEM2", "GPS2", "I2C", "CAN1", "CAN2", "I_O_PWM_OUT",
                             "PPM_SBUS_RC", "DSM_RC", "SBUS_OUT", "USB", "FMU_DEBUG", "I_O_DEBUG")])),
    ("J12", "GPS_M10", "GPS + compass: Holybro M10, IST8310, 10-pin (SKU 12040)", 50.8, 152.4,
     {"1": "GPS_5V", "2": "GPS_RX", "3": "GPS_TX", "4": "MAG_SCL", "5": "MAG_SDA", "6": "SAFETY_SW",
      "7": "SAFETY_LED", "8": "SAFETY_3V3", "9": "BUZZER", "10": "GND"}),
    ("J13", "ELRS_RX", "ELRS receiver: RadioMaster RP3-H (on TELEM3)", 50.8, 190.5,
     {"5V": "ELRS_5V", "GND": "GND", "TX": "ELRS_TX", "RX": "ELRS_RX", "EXTV": NC}),
]
# ArduPilot Quad X, confirmed only by a props-off motor test
QUADX = [("front-right", "CCW"), ("rear-left", "CCW"), ("front-left", "CW"), ("rear-right", "CW")]
for i, (pos, spin) in enumerate(QUADX):
    n, y = i + 1, 43.18 + i * 30.48
    PARTS.append(("J%d" % (2 + n), "ESC", "ESC %d / AUX %d / %s: XRotor PRO 50A" % (n, n, spin), 236.22, y,
                  {"VP": "VBAT_ESC", "VN": "GND", "SIG": "MOT%d_PWM" % n, "SGND": "GND",
                   "A": "M%d_A" % n, "B": "M%d_B" % n, "C": "M%d_C" % n}))
    PARTS.append(("J%d" % (6 + n), "Motor", "Motor %d %s %s: Avenger 3110 730KV" % (n, pos, spin), 307.34, y,
                  {"A": "M%d_A" % n, "B": "M%d_B" % n, "C": "M%d_C" % n}))

NOTES = [
    (20.32, 17.78, 2.54, True, "SBI drone, Phase 1: wiring schematic"),
    (20.32, 22.86, 1.5, False, "Battery disconnected for all assembly and continuity checks.  "
                               "As of 2026-09-30.  Ground truth: wiring/wiring-table.md"),
    (210.82, 152.4, 1.27, False, "\n".join([
        "NET GLOSSARY",
        "BAT_P, BAT_N: battery + and - to the PM07 XT60 lead (XT60 plug).",
        "VBAT_ESC, GND: PM07 B+ and GND pads to each ESC (soldered). The PM07 joins its",
        "    input to these inside the board, through its current sensor.",
        "Mn_A, Mn_B, Mn_C: ESC n to motor n phase leads (3.5 mm bullets). Phase order is arbitrary.",
        "AUXn_PWM: 6C FMU PWM OUT channel n to PM07 FMU-PWM-in (10-pin cable).",
        "MOTn_PWM: PM07 FMU-PWM-out Sn to ESC n signal lead (plug-in).",
        "SERVO_RAIL: VDD_Servo in the 10-pin cable. Unpowered: PM07 supplies no 5 V there.",
        "FC_5V, BATT_CURR, BATT_VOLT: PM07 PWR1 to 6C POWER1 (6-pin cable).",
        "GPS_5V, GPS_TX, GPS_RX, MAG_SCL, MAG_SDA, SAFETY_*, BUZZER: M10 to 6C GPS1 (10-pin cable).",
        "ELRS_5V, ELRS_TX, ELRS_RX: RP3-H to 6C TELEM3 (custom cable).",
        "    xxx_TX is sent by the peripheral; xxx_RX is received by it.",
        "",
        "MOTOR MAP (ArduPilot Quad X; confirm with a props-off motor test)",
        "1 front-right CCW, AUX 1 (SERVO9)      2 rear-left CCW, AUX 2 (SERVO10)",
        "3 front-left CW, AUX 3 (SERVO11)       4 rear-right CW, AUX 4 (SERVO12)",
        "Spin direction is set by each ESC's DIP switch.",
        "",
        "NO-CONNECT FLAGS",
        "6C: each unused port is one pin. TELEM1 is kept for a SiK radio, TELEM2 for the",
        "    Phase 2 companion computer. I/O PWM OUT (MAIN) is unused: motors are on AUX.",
        "6C TELEM3 pins 4-5: not connected on the 6C.",
        "PM07: PWR2, I/O PWM-in, M1-M8 holes, CAP&ADC unused. FMU-PWM-out S5-S8: four ESCs only.",
        "M10 GPS pins 6-9 are NC on the V2 unit (no safety switch, buzzer or LED).",
        "Battery balance lead: charger only. RP3-H Ext-V: unused.",
        "",
        "ArduPilot: SERVO9-12_FUNCTION = 33-36, SERVO1-4_FUNCTION = 0, SERIAL5_PROTOCOL = 23.",
        "ESC power lead gauge: TBD."])),
]


# ---------------------------------------------------------------- schematic
def schematic(root):
    geo = {name: geometry(sym) for name, sym in SYMBOLS.items()}
    out = ['(kicad_sch (version 20231120) (generator "eeschema") (generator_version "8.0")',
           '  (uuid %s)' % q(root), '  (paper "A3")', '  (lib_symbols']
    for name, sym in SYMBOLS.items():
        out.append("\n".join("    " + line for line in symbol_sexpr(name, sym, LIB + ":").splitlines()))
    out.append('  )')
    stub = 5.08
    for ref, sname, value, X, Y, nets in PARTS:
        g = geo[sname]
        pins = {p[0]: p for p in g["pins"]}
        missing = set(pins) - set(nets)
        extra = set(nets) - set(pins)
        if missing or extra:
            raise ValueError("%s: pins without a net or NC %s, unknown pins %s" % (ref, missing, extra))
        for num, net in nets.items():
            _, _, _, side, px, py = pins[num]
            ax, ay = X + px, Y - py                    # symbol y is up, schematic y is down
            if net is None:
                out.append('  (no_connect (at %s %s) (uuid %s))' % (f(ax), f(ay), q(uid(ref, num, "nc"))))
                continue
            ex = ax - stub if side == "L" else ax + stub
            out.append('  (wire (pts (xy %s %s) (xy %s %s)) (stroke (width 0) (type default)) (uuid %s))'
                       % (f(ax), f(ay), f(ex), f(ay), q(uid(ref, num, "w"))))
            angle, just = (180, "right") if side == "L" else (0, "left")
            out.append('  (label %s (at %s %s %d) (fields_autoplaced yes) '
                       '(effects (font (size 1.27 1.27)) (justify %s bottom)) (uuid %s))'
                       % (q(net), f(ex), f(ay), angle, just, q(uid(ref, num, "l"))))
    for i, (x, y, size, bold, s) in enumerate(NOTES):
        out.append('  (text %s (exclude_from_sim no) (at %s %s 0) (effects (font (size %s %s)%s) '
                   '(justify left top)) (uuid %s))'
                   % (q(s), f(x), f(y), f(size), f(size), " (bold yes)" if bold else "", q(uid("note", i))))
    for ref, sname, value, X, Y, nets in PARTS:
        g = geo[sname]
        out.append('  (symbol (lib_id %s) (at %s %s 0) (unit 1) (exclude_from_sim no) (in_bom yes) '
                   '(on_board yes) (dnp no) (uuid %s)' % (q(LIB + ":" + sname), f(X), f(Y), q(uid(ref))))
        out.append('    (property "Reference" %s (at %s %s 0) %s)' % (q(ref), f(X), f(Y - g["top"] - 3.81), FONT))
        out.append('    (property "Value" %s (at %s %s 0) %s)' % (q(value), f(X), f(Y - g["top"] - 1.27), FONT))
        for prop in ("Footprint", "Datasheet"):
            out.append('    (property "%s" "" (at %s %s 0) %s)' % (prop, f(X), f(Y), FONT_HIDE))
        out.append('    (property "Description" %s (at %s %s 0) %s)'
                   % (q(SYMBOLS[sname]["desc"]), f(X), f(Y), FONT_HIDE))
        for p in g["pins"]:
            out.append('    (pin %s (uuid %s))' % (q(p[0]), q(uid(ref, p[0], "pin"))))
        out.append('    (instances (project %s (path %s (reference %s) (unit 1))))'
                   % (q(LIB), q("/" + root), q(ref)))
        out.append('  )')
    out.append('  (sheet_instances (path "/" (page "1")))')
    out.append(')')
    return "\n".join(out) + "\n"


def write(path, text):
    with open(path, "w", encoding="utf-8", newline="\n") as fh:
        fh.write(text)


if __name__ == "__main__":
    here = os.path.dirname(os.path.abspath(__file__))
    root = uid("root")
    lib = ['(kicad_symbol_lib (version 20231120) (generator "kicad_symbol_editor") (generator_version "8.0")']
    for name, sym in SYMBOLS.items():
        lib.append("\n".join("  " + line for line in symbol_sexpr(name, sym).splitlines()))
    lib.append(")")
    write(os.path.join(here, LIB + ".kicad_sym"), "\n".join(lib) + "\n")
    write(os.path.join(here, LIB + ".kicad_sch"), schematic(root))
    write(os.path.join(here, "sym-lib-table"),
          '(sym_lib_table\n  (version 7)\n  (lib (name "%s")(type "KiCad")(uri "${KIPRJMOD}/%s.kicad_sym")'
          '(options "")(descr "SBI drone system-level blocks"))\n)\n' % (LIB, LIB))
    write(os.path.join(here, LIB + ".kicad_pro"), json.dumps(
        {"meta": {"filename": LIB + ".kicad_pro", "version": 1},
         "sheets": [[root, "Root"]], "boards": [], "libraries": {"pinned_symbol_libs": []}},
        indent=2) + "\n")
    n_labels = sum(1 for p in PARTS for v in p[5].values() if v)
    n_nc = sum(1 for p in PARTS for v in p[5].values() if v is None)
    print("symbols %d  labels %d  no-connects %d" % (len(PARTS), n_labels, n_nc))

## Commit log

2026-10-02 Add Phase 1 parts list and wiring package
    - SBI_Drone_Phase1_Parts.xlsx: Phase 1 parts with vendor, price
    (checked 2026-09-30), link, and a justification for each part
    - wiring/: block diagram, KiCad schematic, wiring table, and
    build.py, which runs ERC and the netlist check and re-exports
    the figures
    - README: what Phase 1 is and where things are
    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
    [SBI_Drone_Phase1_Parts.xlsx, sbi_phase1.kicad_sch]
2026-10-02 Restyle the Phase 1 parts spreadsheet
    Banded rows, wrapped text with row heights set so justifications
    show in full, stronger header and section band, boxed summary with
    remaining budget coloured green/red, frozen item columns, and a
    landscape fit-to-width print setup. No values, formulas or links
    changed.
    [SBI_Drone_Phase1_Parts.xlsx]
